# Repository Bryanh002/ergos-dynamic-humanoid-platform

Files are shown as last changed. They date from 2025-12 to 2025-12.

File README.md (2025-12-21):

```
███████╗██████╗  ██████╗  ██████╗ ███████╗
██╔════╝██╔══██╗██╔════╝ ██╔═══██╗██╔════╝
█████╗  ██████╔╝██║  ███╗██║   ██║███████╗
██╔══╝  ██╔══██╗██║   ██║██║   ██║╚════██║
███████╗██║  ██║╚██████╔╝╚██████╔╝███████║
╚══════╝╚═╝  ╚═╝ ╚═════╝  ╚═════╝ ╚══════╝
```
### Embodied Reinforcement Gait Optimization System
---

## 🧠 Overview
ERGOS is meant to be a low-cost, open-source platform designed for dynamic humanoid robotics research. It serves as a ROS2-based control environment that integrates serial servo hardware with Reinforcement Learning (RL) techniques. The primary goal of ERGOS is to develop and optimize dynamic, stable gait patterns for bipedal systems, demonstrating advanced movement capabilities on an economical, self-contained hardware platform. Here is a photo of ERGOS's current design:

<p align="center">
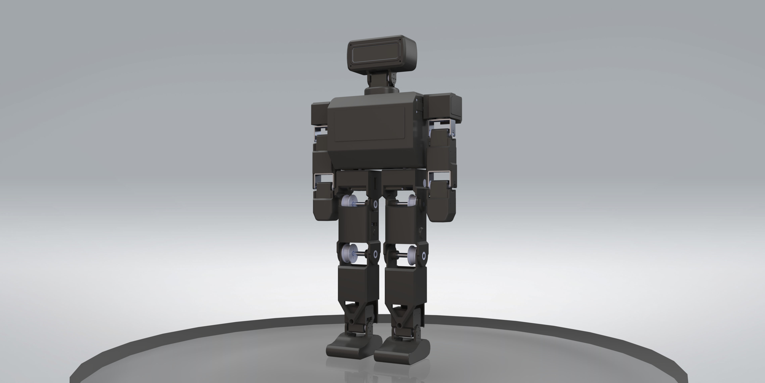
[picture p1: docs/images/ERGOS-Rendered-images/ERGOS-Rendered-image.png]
  
  <br>
</p>

---

## 🗺️ Repository Map

- **Hardware**
  - [`mechanical/`](mechanical/) — CAD, renders
  - [`electrical/`](electrical/) — schematics, PCB, BOM
- **Software**
  - [`software/`](software/) — firmware, ROS 2 packages, tools, simulations
- **Docs**
  - [`docs/`](docs/) — BOM, images, datasheets

---

## ⚙️ Features & Capabilities  
*(Planned and In Progress)*

### Mechanical System
- Custom humanoid mechanical design
- Belt-driven actuation using HTD-3M pulleys (18T–30T) for joint-specific torque amplification
- 3D-printed structural housings optimized for low cost and rapid iteration
- Modular joint architecture to support future actuator and transmission upgrades

### Electronics & Power
- Custom PCB featuring an ESP32-S3 for real-time servo communication
- Custom full-duplex to half-duplex TTL transceiver for serial servo bus control
- On-board power management from a 3S 8400 mAh LiPo battery
- Custom power and communication harness backbone for distributed serial servos
- Jetson Orin Nano as the primary compute module, interfacing with the MCU for control and perception workloads

### Dynamic Locomotion (Reinforcement Learning) *(Future)*
- Reinforcement learning-based locomotion control for stable, adaptive walking
- Simulation-first training pipeline with planned sim-to-real transfer onto physical hardware
- Architecture designed to support experimentation with different control formulations and reward structures

### Environmental Perception *(Future)*
- Vision system integration for obstacle detection and terrain awareness
- Planned fusion of perception outputs into locomotion and navigation policies

### Speech & Human Interaction *(Future)*
- On-board large language model (LLM) for voice-based command interpretation
- Natural-language interface for high-level behavior control and human–robot interactions

---

## 🧩 System Architecture

<p align="center">
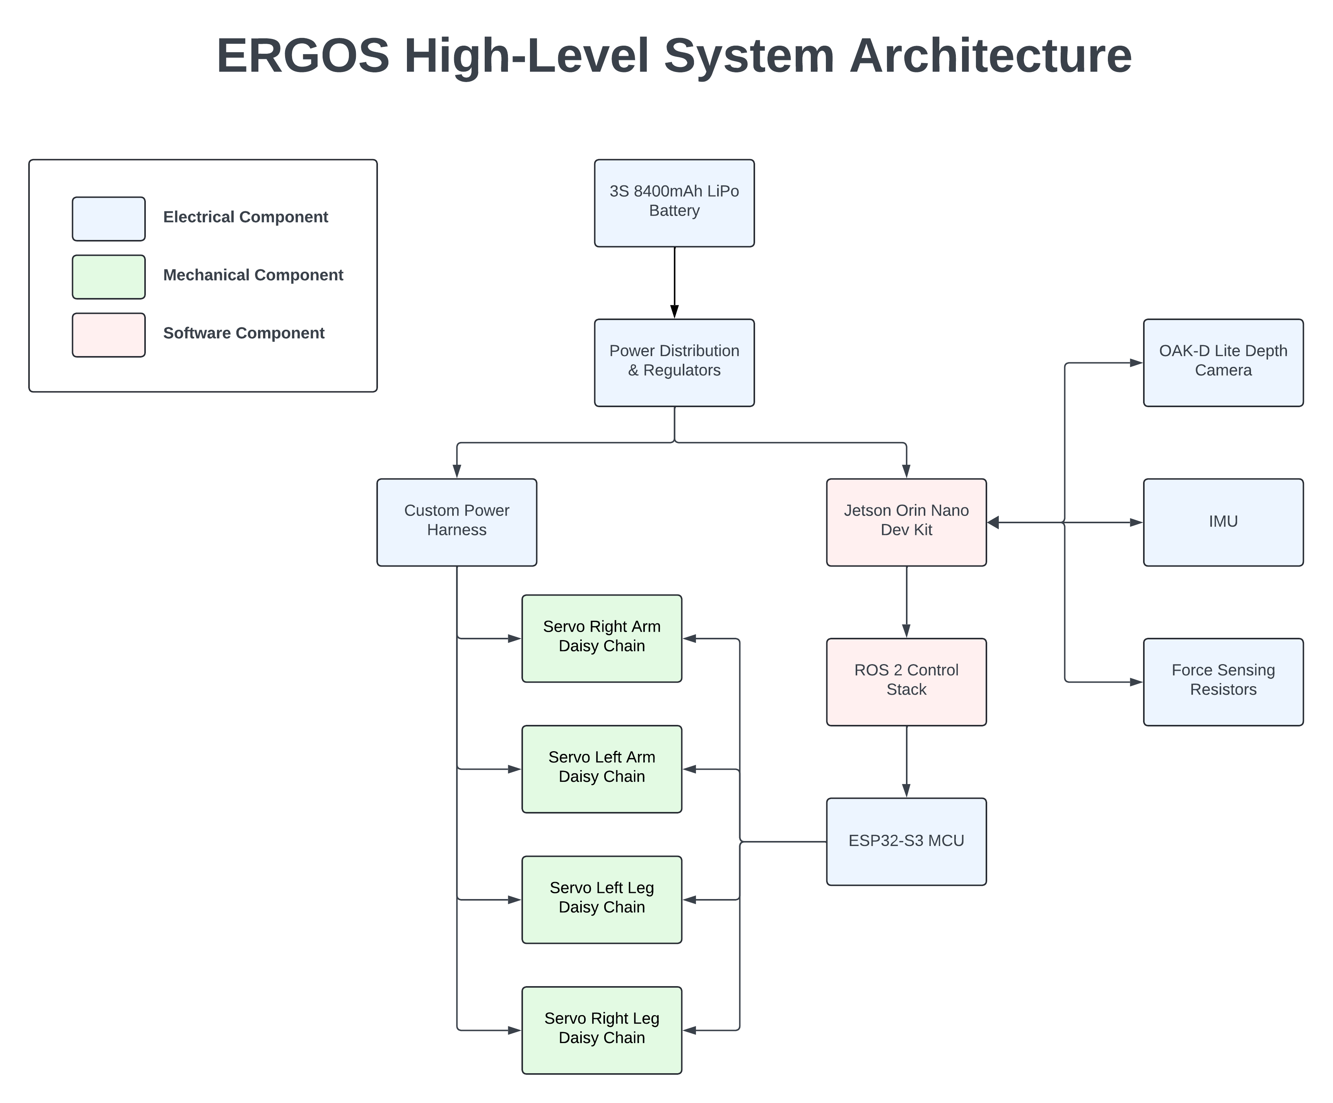
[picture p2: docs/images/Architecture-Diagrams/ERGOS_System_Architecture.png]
  
  <br>
</p>

**Figure 1.** High-level system architecture of the ERGOS humanoid platform. The system is powered by a centralized 3S LiPo battery, which feeds a custom power distribution and regulation stage. This stage supplies both the actuator subsystem and the main compute unit. High-level perception, planning, and reinforcement learning policies are executed on the Jetson Orin Nano within a ROS 2-based control stack. Control commands are transmitted to an ESP32-S3 real-time controller, which handles low-level actuation and interfaces directly with modular servo daisy chains. Sensor inputs, including depth vision, inertial measurements, and foot force sensing, are processed on the Jetson and integrated into the control pipeline. Detailed mechanical, electrical, and software architectures are documented in subsystem-specific sections.

---

## 🧪 Development Phases
1. **Phase 1 — Hardware Creation**  
   Finalize CAD design and PCB for servo control and power distribution.

3. **Phase 2 — Reinforcement Learning Simulation**  
   Develop a simulation environment for dynamic walking using RL.  
   *(Likely frameworks: PyTorch, custom physics simulation, or Isaac Gym)*

4. **Phase 3 — Real-World Testing**  
   Transfer trained model to the Jetson Orin Nano for live walking experiments.

5. **Phase 4 — Vision and Speech Integration**  
   Add camera input for object detection and LLM for high-level control.

---

## 🧠 Technical Summary
- **Programming Language:** Python (planned)
- **Frameworks:** TBD (PyTorch or TensorFlow for RL; ROS2 possible integration)
- **Hardware:** Jetson Orin Nano, ESP32-S3, Feetech STS3235/STS3250 smart servos
- **Design Tools:** SolidWorks (mechanical), Altium Designer (PCB)

---

## 🚀 Getting Started
*(To be updated as the project matures)*

**Planned sections:**
1. Installation requirements (JetPack SDK, Python environment, dependencies)
2. Simulation setup (RL environment)
3. Model training and deployment instructions
4. Hardware configuration and servo connection mapping

---

## 📈 Future Work
- WIP

---

## 📜 License
This project is open source and released under the **MIT License**.  
See the [LICENSE](LICENSE) file for more information.

---

## 👤 Project Developer
**Bryan Heddle**  
Mechatronics & AI Systems Engineering Student — *Western University*  

---

## 💡 Acknowledgments
Special thanks to the open-source robotics community for the tools, documentation, and inspiration that contributed to this project’s foundation.

**Project sponsors:**
- **[Thompson Innovation Fund](https://www.eng.uwo.ca/tc/innovation-fund.html)**
- **[WESEF](https://www.eng.uwo.ca/departments-units/finance-stores/undergrads/wesef.html)**
- **[Luxonis](https://www.luxonis.com/)**
---

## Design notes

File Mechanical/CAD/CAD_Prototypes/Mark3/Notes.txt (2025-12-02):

Make M2 screws to M3 (ones that connects torso to jetson holder)

Make 60KG servo wire holes

Make 12 mm bearing

Make wiring paths

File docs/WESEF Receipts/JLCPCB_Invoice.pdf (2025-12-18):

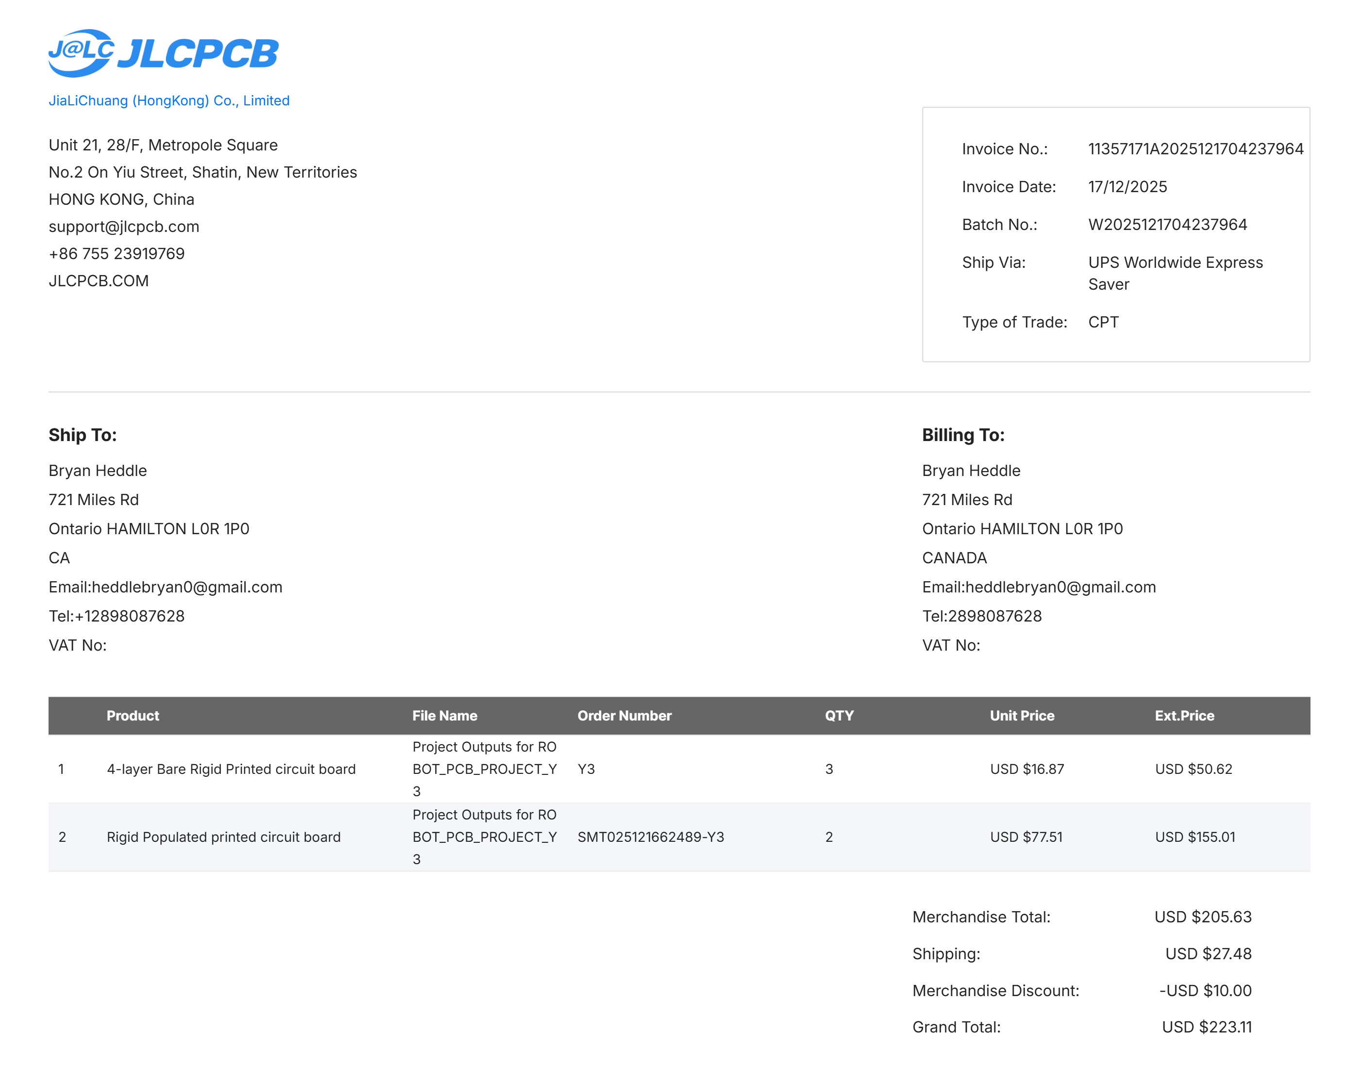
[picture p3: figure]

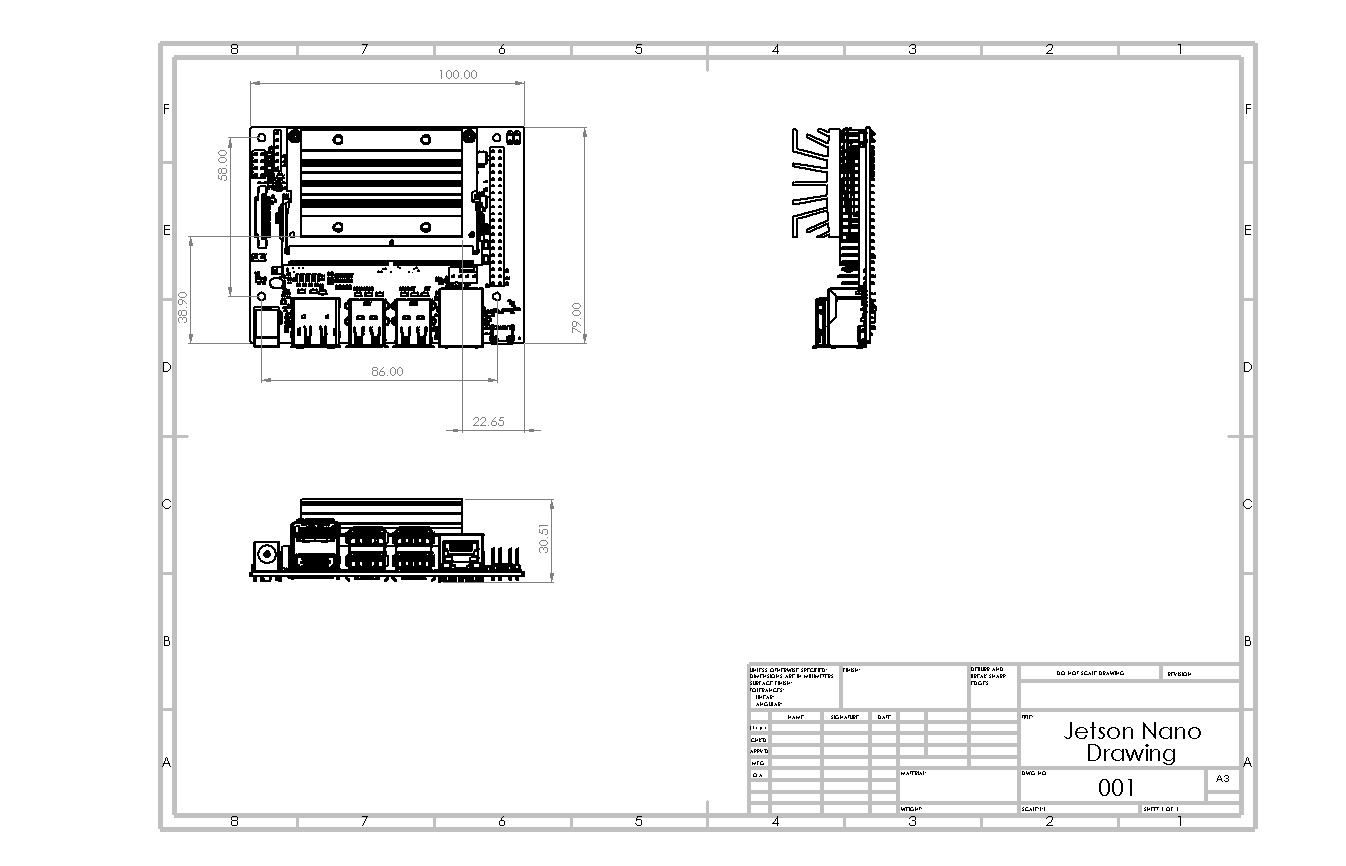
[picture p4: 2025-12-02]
Mechanical/CAD/CAD_Prototypes/Mark3/Drawings/Jetson_nano_4GB_Drawing.JPG

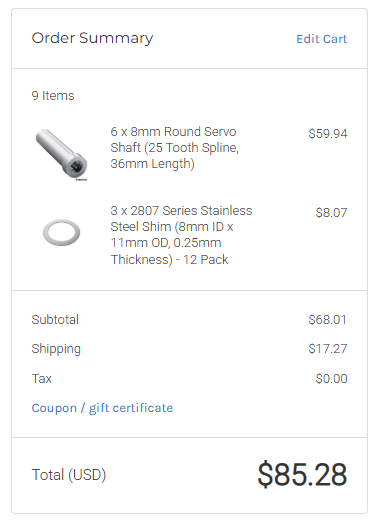
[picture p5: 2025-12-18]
docs/WESEF Receipts/Bilda-ServoShaft&Washers.PNG

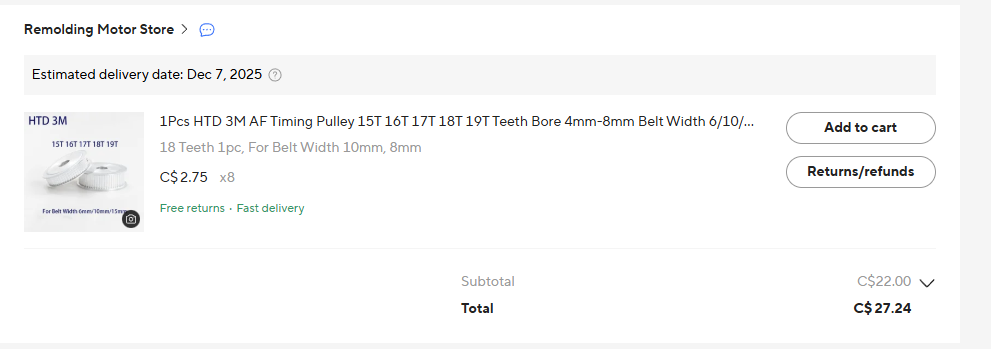
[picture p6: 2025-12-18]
docs/WESEF Receipts/AliExpress-18T-Pulley.PNG

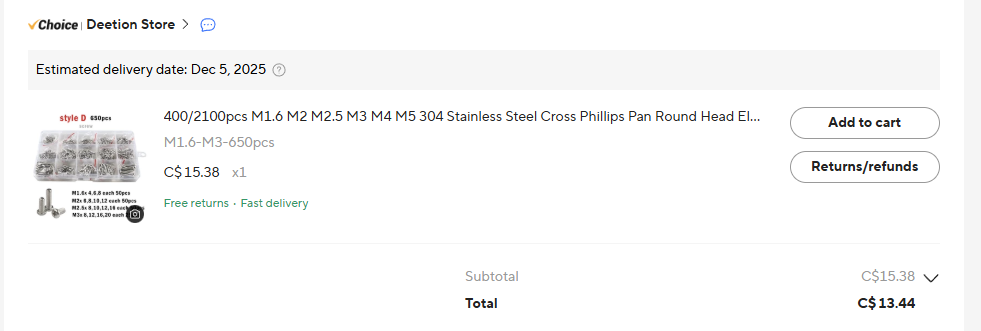
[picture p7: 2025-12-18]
docs/WESEF Receipts/AliExpress-ScrewKit.PNG

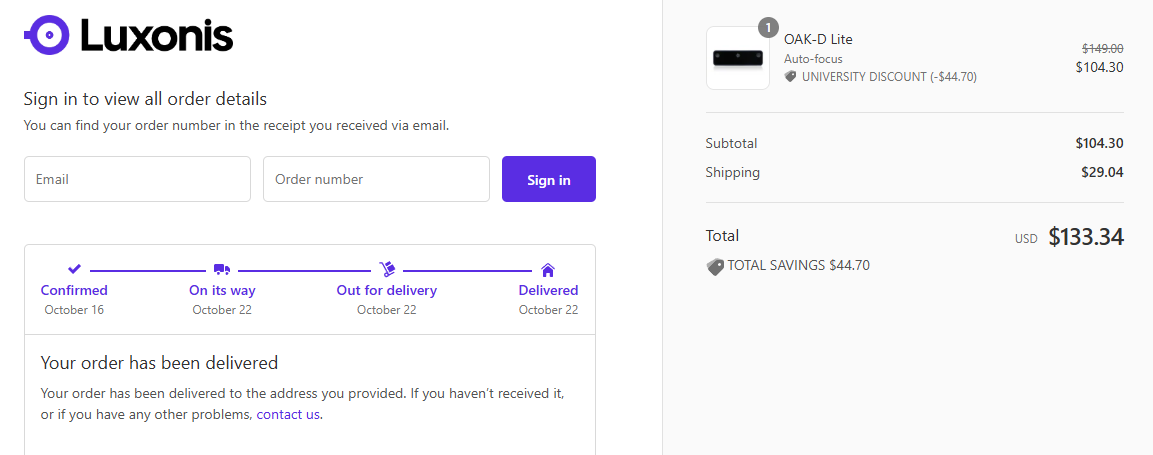
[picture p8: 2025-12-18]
docs/WESEF Receipts/Luxonis-OAK-D-Lite.PNG

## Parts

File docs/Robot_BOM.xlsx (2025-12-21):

Part | Product Link | Description | Quantity | Cost | Total Cost + Tax | Final Cost
MECHANICAL |  |  |  |  |  | $2960.02
STS3250 50kg-cm TTL Dual-shaft | https://www.feetechrc.com/en/562636.html | High-torque smart servo used for the hip, knee, and shoulder joints to handle the primary load-bearing and dynamic movement required for humanoid locomotion. | 14 | $65.81 | $1041.11
STS3235 30kg-cm TTL Dual-shaft | https://www.feetechrc.com/en/12v-30kg-metal-shell-metal-tooth-iron-core-motor-magnetic-coding-double-shaft-ttl-series-steering-gear.html | Medium-torque smart servo used for arm and neck joints where lower torque is sufficient but precise control is still required for coordinated movement. | 6 | $57.86 | $392.29
8mm Round Servo Shaft | https://www.gobilda.com/8mm-round-servo-shaft-25-tooth-spline-36mm-length/ | Custom shafts used to transfer motion between servo outputs and pulley assemblies, enabling reliable and backlash-free mechanical transmission. | 6 | $9.99 | $67.73
HTD 3M 18T Timing pulley | https://www.aliexpress.com/item/1005007456973949.html | Serves as the driving pulley in the belt transmission system, translating servo rotation. | 8 | $3.02 | $27.30
HTD 3M 30T Timing Pulley | https://www.aliexpress.com/item/1005009686443539.html | Acts as the driven pulley in the gear reduction setup, increasing torque at each joint. | 4 | $6.79 | $30.69
8mm ID 11 mm OD Washers | https://www.gobilda.com/2807-series-stainless-steel-shim-8mm-id-x-11mm-od-0-25mm-thickness-12-pack/ | Used to reduce axial friction and prevent rubbing between rotating parts and stationary brackets. | 1 | $2.69 | $3.04
MR95ZZ Bearings | https://www.amazon.ca/uxcell-Bearings-8x12x3-5mm-Miniature-Precision/dp/B0CM6G9ZKZ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 | Smaller bearings used in compact joint housings where load and speed requirements are moderate. | 1 | $16.29 | $18.41
PLA | https://www.amazon.ca/ELEGOO-Filament-Dimensional-Accuracy-Cardboard/dp/B0C8J1JZMT?s=industrial | 3D printing material used for lightweight housings and custom mounts throughout the robot prototype to allow iterative design, it's likely I'll need lots of PLA due to continous prints, and like mentioned, fixes. | 2 | $44.99 | $101.68
Loctite 638 | https://www.amazon.ca/Loctite-21448-Strength-Retaining-Compound/dp/B000O01EV0 | High-strength retaining compound for securing shafts, pulleys, and bearings, preventing slippage under dynamic loads. | 1 | $24 | $27.12
ELECTRICAL |  |  |  |  | 0
3s lipo 8400mah 11.1v 120c | https://www.amazon.ca/DXF-Battery-Hardcase-Airplane-Helicopter/dp/B09TDFVWHS | Primary power source for servos, Jetson Orin Nano, and sensors; provides sufficient current delivery for high-demand movements. | 1 | $99.99 | $112.99
PCB | JLCPCB [view quote image] | Central power and communication hub distributing regulated voltage and serial signals between servos, Jetson, and sensors. | 1 | $284.00 | $320.92
PCB components | https://www.digikey.ca/short/0zvnp1rd | all components required for PCB | 1 | $183 | $206.79
 |  |  |  |  | 0
SOFTWARE
Jetson Orin Nano | https://www.amazon.ca/NVIDIA-Jetson-Orin-Nano-Developer/dp/B0BZJTQ5YP | Main onboard computer handling perception, reinforcement learning, and motion planning in real time. | 1 | $344.95 | $389.79
OAK-D Lite | https://shop.luxonis.com/products/oak-d-lite-1 | Provides depth and RGB vision for environmental awareness, obstacle detection, and balance correction. Received 30% discount from Luxonis reducing the price from $209.8 to $147 CAD. | 1 | $146.84 | $165.93
Patriot P320 128GB SSD | https://www.amazon.ca/dp/B0D4RD18YV?ref=ppx_yo2ov_dt_b_fed_asin_title&th=1 | High-speed storage for AI models, video frames, and system data during real-time inference and logging. | 1 | $47.99 | $54.23

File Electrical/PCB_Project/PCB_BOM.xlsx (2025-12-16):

Line # | Name | Description | Designator | Revision ID | Quantity | Manufacturer 1 | Manufacturer Part Number 1 | Manufacturer Lifecycle 1 | Supplier 1 | Supplier Part Number 1 | Supplier Unit Price 1 | Supplier Subtotal 1 | JLCPCB
1 | SML-LX1206IC-TR | LED Red, 65 mW, -40 to 85 degC, 2-Pin SMD, RoHS, Tape and Reel | BLINK, PWR | CMP-2000-07123-1 | 2 | Lumex | SML-LX1206IC-TR | Volume Production | DigiKey | 67-1356-2-ND | 0.22 | 0.44
2 | 1825910-6 | Switch Push Button OFF (ON) SPST Round Button 0.05A 24VDC Momentary Contact PC Pins Thru-Hole | Boot1, Reset1 |  | 2 | TE Connectivity | 1825910-6 | Volume Production | Digikey | 450-1650-ND | 0.13 | 0.26
3 | CC0805KRX7R9BB104 | CAP CER 0.1UF 50V X7R 0805 | C1, C2, C5, C6, C7, C8, C9, C10, C11, C12, C13, C14, C15, C16, C17, C18, C19, Cboot1, Cboot2 | CMP-2100-03606-3 | 19 | Yageo Group | CC0805KRX7R9BB104 | Volume Production | Digikey | 311-1140-2-ND | 0.012 | 0.23
4 | C0805C105K5RACTU |  | C3, C4 | CMP-2007-03236-1 | 2 | KEMET | C0805C105K5RACTU | Volume Production | Mouser | 80-C0805C105K5R | 0.82507 | 1.65
5 | CGA4C2C0G1H822J060AA | Cap Ceramic 8.2nF 50V C0G 5% Pad SMD 0805 +125°C Automotive T/R | Ccomp1 | CMP-08246-000542-1 | 1 | TDK | CGA4C2C0G1H822J060AA | Volume Production | Arrow Electronics | CGA4C2C0G1H822J060AA | 0.01538 | 0.01538
6 | GRM1555C1H391JA01J | Chip Multilayer Ceramic Capacitors for General Purpose, 0402, 390pF, C0G, 30ppm/°C, 5%, 50V | Ccomp2 | CMP-2008-04006-2 | 1 | Murata | GRM1555C1H391JA01J | Volume Production | Mouser | 81-GRM1555C1H391JA1J | 0.13984 | 0.13984
7 | CL32A106KBJNNNE | Cap Ceramic 10uF 50V X5R ±10% SMD 1210 +85°C Embossed T/R | Cin1, Cin2 | CMP-13271-001337-1 | 2 | Samsung Electro-Mechanics | CL32A106KBJNNNE | Volume Production | DigiKey | 1276-3363-1-ND | 0.72718 | 1.45
8 | CL32B106KBJNNWE | Cap Ceramic 10uF 50V X7R ±10% SMD 1210 +125°C Embossed T/R | Cout1, Cout2, Cout3 | CMP-13271-004028-1 | 3 | Samsung Electro-Mechanics | CL32B106KBJNNWE | Volume Production | DigiKey | 1276-3388-6-ND | 0.30765 | 0.92296
9 | GRM1885C1H101JA01D | SMD Capacitor C0G(EIA) with Capacitance: 100pF Tol. 5%. Rated Voltage: 50Vdc | Csns | CMP-001-00083-1 | 1 | Murata | GRM1885C1H101JA01D | Not Recommended for New Design | DigiKey | 490-1427-2-ND | 0.08 | 0.08
10 | C1608C0G1E472J080AA | Multilayer Ceramic Capacitors 4.7nF ±5% 25V C0G SMD 0603 | Css | CMP-08246-004785-1 | 1 | TDK | C1608C0G1E472J080AA | Not Recommended for New Design | DigiKey | 445-2712-1-ND | 0.30765 | 0.30765
11 | GRM188R61C106MA73D | Chip Multilayer Ceramic Capacitors for General Purpose, 0603, 10uF, X5R, 15%, 20%, 16V | Cvcc | CMP-2006-02814-2 | 1 | Murata | GRM188R61C106MA73D | Volume Production | Mouser | 81-GRM188R61C106MA3D | 0.32164 | 0.32164
12 | GRM155R71C104KA88D | SMD Capacitor X7R(EIA) with Capacitance: 0.10uF Tol. 10%. Rated Voltage: 16Vdc | Cvin | CMP-001-00084-1 | 1 | Murata | GRM155R71C104KA88D | Volume Production | DigiKey | 490-3261-2-ND | 0.1 | 0.1
13 | SMBJ13A-13-F | 400 W 13 V Uni-Directional SMT Transient Voltage Suppressor Diode - DO-214AA | D2, D3, D4, D5 |  | 4 | Diodes Inc. | SMBJ13A-13-F | Volume Production | DigiKey | SMBJ13A-FDITR-ND | 0.28 | 1.12
14 | XBS053V15R-G | Diode Schottky 20V 500mA Surface Mount SOD-523 | Dboot | CMP-004-00031-1 | 1 | Torex | XBS053V15R-G | Volume Production | Mouser | 865-XBS053V15R-G | 1.07 | 1.07
15 | 3568 |  | F2, F3, F4, F5 | CMP-2000-05464-2 | 4 | Keystone | 3568 | Volume Production | Future Electronics | 4264032 | 1.06 | 4.22
16 | B3B-XH-A | Connector Header Through Hole 3 position 0.098 (2.50mm) | J1, J2, J3, J4 |  | 4 | JST Sales America Inc. | B3B-XH-A | Volume Production | DigiKey | 455-2248-ND | 0.11 | 0.44
17 | XT90PW-M | Socket; DC supply; XT90; male; PIN: 2; on PCBs; THT; Colour: yellow | J5 |  | 1 | DFRobot | FIT0588 | Volume Production | DigiKey | 1738-1438-ND | 3.9 | 3.9
18 | 1017505 |  | J6, J7 |  | 2 | Pheonix Contact | 1017505 | Volume Production | DigiKey | 277-17516-ND | 1.99 | 3.98
19 | KLDX-0202-B | 3 Conductor Power Jack, 2 break 2 aux contacts | J8 | CMP-0256-00001-1 | 1 | Kycon | KLDX-0202-B | Volume Production | DigiKey | 2092-KLDX-0202-B-ND | 0.96492 | 0.96492
20 | M20-9990246 | 2.54mm (0.1) Pitch SIL Vertical Throughboard Pin Header, 6.1mm mating pin height, tin, 2 contacts | J9, J10 | CMP-002-00071-1 | 2 | Harwin Inc. | M20-9990246 | Volume Production | DigiKey | 952-2262-ND | 0.1 | 0.2
21 | XAL6060-472MEC | Power inductor, shielded, 20% tol, SMT, RoHS, halogen-f | L1 | CMP-006-00021-1 | 1 | Coilcraft | XAL6060-472MEC | Volume Production | Mouser | 994-XAL6060-472MEC | 6.82 | 6.82
22 | CSD17571Q2 | MOSFET N-CH 30V 22A 6SON | Q1, Q2 | CMP-04962-000062-1 | 2 | Texas Instruments | CSD17571Q2 | Volume Production | Mouser | 595-CSD17571Q2 | 0.93695 | 1.87
23 | CRCW08054K70FKEA | RES Thick Film, 4.7kΩ, 1%, 0.125W, 100ppm/°C, 0805 | R1, R2, R3, R4, R5 | CMP-2100-03615-2 | 5 | Vishay | CRCW08054K70FKEA | Volume Production | RS (Formerly Allied Electronics) | 70201241 | 0.00839 | 0.04195
24 | RMCF0603FG47R0 | 47Ω ±1% 0.1W 0603 Thick Film Chip Resistor AEC-Q200 compliant | R6, R8, R10, R12 | CMP-26527-000678-1 | 4 | Stackpole Electronics | RMCF0603FG47R0 | Volume Production | Avnet | RMCF0603FG47R0 | 0.00266 | 26.57
25 | RMCF1206FG10K0 | 10kΩ ±1% 0.25W 1206 Thick Film Chip Resistor AEC-Q200 compliant | R7, R9, R11, R13, R14, R15 | CMP-26527-002036-1 | 6 | Stackpole Electronics | RMCF1206FG10K0 | Volume Production | DigiKey | 738-RMCF1206FG10K0CT-ND | 0.04055 | 0.40554
26 | CRCW04025K36FKED | RES Thick Film, 5.36kΩ, 1%, 0.063W, 100ppm/°C, 0402 | Rcomp | CMP-1011-00593-3 | 1 | Panasonic | ERJ-2RKF5361X | Volume Production | Arrow Electronics | ERJ-2RKF5361X | 0.00406 | 0.00406
27 | CRCW040211K0FKED | RES Thick Film, 11kΩ, 1%, 0.063W, 100ppm/°C, 0402 | Rfbb | CMP-2002-08157-2 | 1 | Vishay | CRCW040211K0FKED | Volume Production | DigiKey | 541-11.0KLCT-ND | 0.13984 | 0.13984
28 | 160K 1% 0603(1608) | 160K 0.1W 1% 0603 (1608 Metric) SMD | Rfbt | CMP-1012-00757-1 | 1 | Vishay | CRCW0603160KFKEA | Volume Production | Arrow Electronics | CRCW0603160KFKEA | 0.0014 | 0.0014
29 | CRCW040210R0FKED |  | Risns-, Risns+ | CMP-2002-08143-1 | 2 | Vishay | CRCW040210R0FKED | Volume Production | Mouser | 71-CRCW0402-10-E3 | 0.02237 | 0.22375
30 | CRCW0402100KFKED | RES Thick Film, 100kΩ, 1%, 0.063W, 100ppm/°C, 0402 | Rpg | CMP-2002-08123-3 | 1 | Vishay Dale | CRCW0402100KFKED | Volume Production | DigiKey | 541-100KLTR-ND | 0.1 | 0.1
31 | PRL1632-R010-F-T1 | 10 mOhms ±1% 1W Chip Resistor Wide 0612 (1632 Metric), Current Sense Thin Film | Rsns1, Rsns2 | CMP-2003-04764-2 | 2 | Susumu | PRL1632-R010-F-T1 | Volume Production | Mouser | 754-PRL1632-R010-FT1 | 0.65726 | 1.31
32 | RC0201FR-07105KL | 105 kOhms Â±1% 0.05W, 1/20W Chip Resistor 0201 (0603 Metric) Moisture Resistant Thick Film | Rt | CMP-009-00177-1 | 1 | Yageo Group | RC0201FR-07105KL | Volume Production | DigiKey | 311-105KMTR-ND | 0.1 | 0.1
33 | RC0201FR-07162KL | 162 kOhms Â±1% 0.05W, 1/20W Chip Resistor 0201 (0603 Metric) Moisture Resistant Thick Film | Ruvlo1 | CMP-009-00179-1 | 1 | Yageo Group | RC0201FR-07162KL | Volume Production | DigiKey | YAG2428TR-ND | 0.1 | 0.1
34 | RC0201FR-0723K7L | 23.7 kOhms Â±1% 0.05W, 1/20W Chip Resistor 0201 (0603 Metric) Moisture Resistant Thick Film | Ruvlo2 | CMP-009-00178-1 | 1 | Yageo Group | RC0201FR-0723K7L | Volume Production | DigiKey | YAG2524TR-ND | 0.1 | 0.1
35 | CRCW04022R00FKED |  | Rvcc | CMP-2002-08486-1 | 1 | Vishay | CRCW04022R00FKED | Volume Production | Newark | CRCW04022R00FKED | 0.00699 | 0.00699
36 | ESP32-S3-WROOM-1-N4R2 | Bluetooth, WiFi 802.11b/g/n, Bluetooth v5.0 Transceiver Module 2.4GHz PCB Trace Surface Mount | U1 |  | 1 | Espressif Systems | ESP32-S3-WROOM-1-N4R2 | Volume Production | DigiKey | 5407-ESP32-S3-WROOM-1-N4R2TR-ND | 5.28 | 5.28
37 | AP2112K-3.3TRG1 | IC REG LINEAR 3.3V 600MA SOT25 | U2 | CMP-12756-000035-1 | 1 | Diodes Inc. | AP2112K-3.3TRG1 | Volume Production | Arrow Electronics | AP2112K-3.3TRG1 | 0.10642 | 0.10642
38 | BMI323 | No Description Available | U3 |  | 1 | Bosch Sensortec | BMI323 | Volume Production | DigiKey | 828-BMI323TR-ND | 3.27 | 3.27
39 | SN74LVC2T45DCTR | 2-Bit Dual Supply Transceiver with Configurable Voltage-Level Shifting and 3-State Outputs 8-SSOP -40 to 85 | U4, U5 |  | 2 | Texas Instruments | SN74LVC2T45DCTR | Volume Production | DigiKey | 296-16845-2-ND | 0.56 | 1.12
40 | SN74LVC2G04DBVRG4 | IC INVERTER 2CH 2-INP SOT23-6 | U6 | CMP-04903-000086-1 | 1 | Texas Instruments | SN74LVC2G04DBVRG4 | Volume Production | Mouser | 595-74LVC2G04DBVRG4 | 1.09 | 1.09
41 | SN74AHCT1G125DBVT | Single 4.5-V to 5.5-V buffer with TTL-compatible CMOS inputs and 3-state outputs | U7, U8, U9, U10, U11, U12, U13, U14 |  | 8 | Texas Instruments | SN74AHCT1G125DBVT | Volume Production | DigiKey | 296-32243-2-ND | 0.84 | 6.72
42 | TPS43060RTER | IC REG CTRLR BOOST 16WQFN | U15 | CMP-04918-000522-1 | 1 | Texas Instruments | TPS43060RTER | Volume Production | DigiKey | 296-39400-1-ND | 3.97 | 3.97
43 | 105017-0001 | Micro-USB B Receptacle, Right Angle, Bottom Mount, Surface Mount, with Solder Tabs, -30 to 85 degC, 5-Pin USB, RoHS, Tape and Reel | VIN | CMP-2000-05827-1 | 1 | Molex | 105017-0001 | Volume Production | DigiKey | WM1399TR-ND | 0.92 | 0.92

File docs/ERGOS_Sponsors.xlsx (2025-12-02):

Sponsors | Amount | Type | Sponsor Link | Total
Thompson Innovation Fund | $1970 | Funding | https://www.eng.uwo.ca/tc/innovation-fund.html | $2782
Western Engineering Student Engagement Fund | $750 | Funding | https://www.eng.uwo.ca/departments-units/finance-stores/undergrads/wesef.html
Luxonis | $62 | Discount on Product | https://www.luxonis.com/

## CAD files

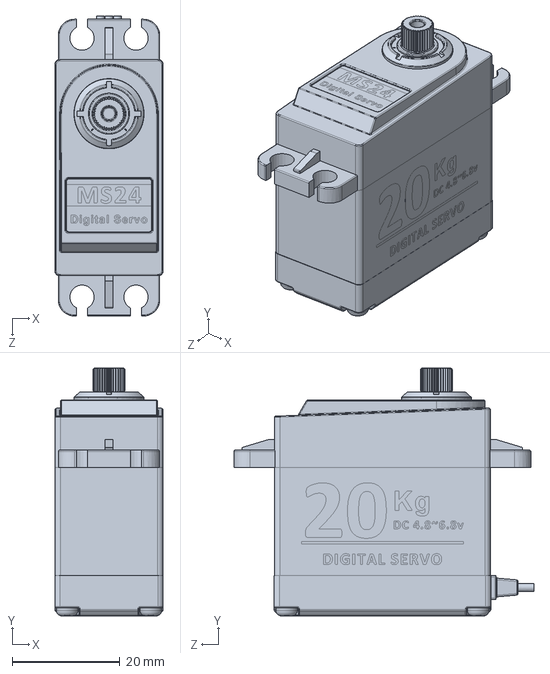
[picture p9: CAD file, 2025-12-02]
Mechanical/CAD/CAD_Prototypes/Mark3/Servos/DS3218MG MS24 Digital Servo 270.SLDPRT
20.1 x 45.9 x 55.6 mm

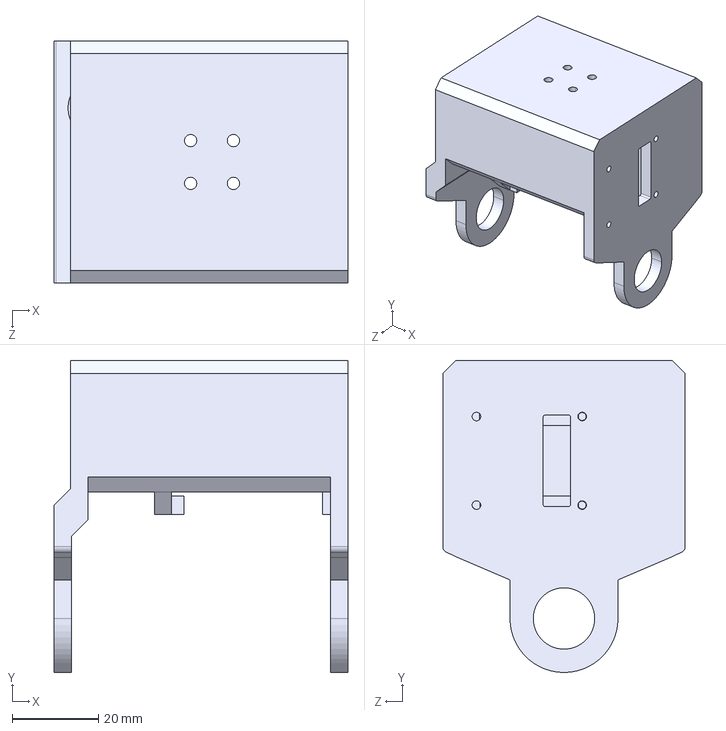
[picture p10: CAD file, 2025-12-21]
Mechanical/CAD/ERGOS_Mark4/Exports/Hip-pulley-housing-left.STEP
68.0 x 72.2 x 56.1 mm

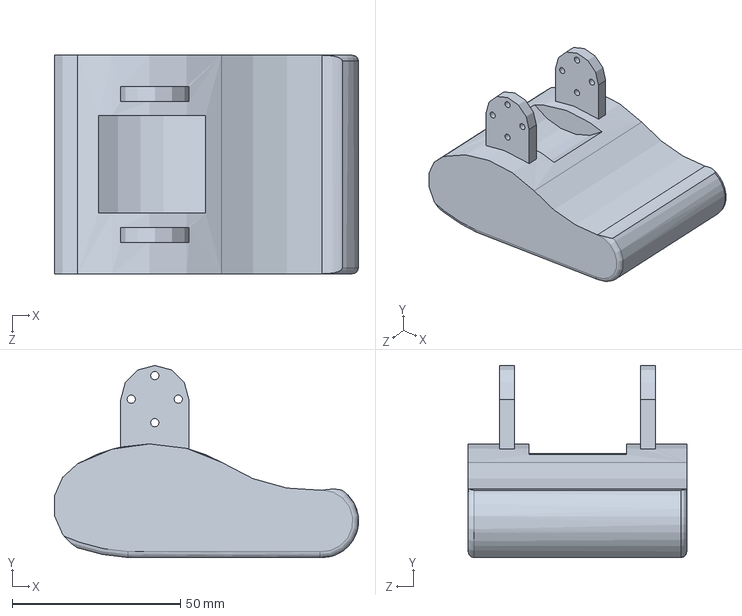
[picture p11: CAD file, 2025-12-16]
Mechanical/CAD/ERGOS_Mark4/Parts/Left-foot.SLDPRT
90.4 x 57.1 x 65.0 mm

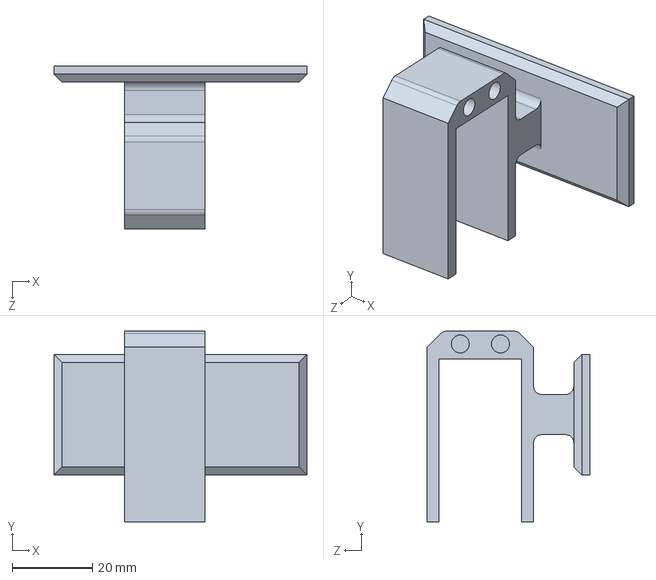
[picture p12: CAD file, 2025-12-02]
Mechanical/CAD/CAD_Prototypes/Mark3/Knee_Connector.SLDPRT
63.0 x 47.5 x 40.5 mm

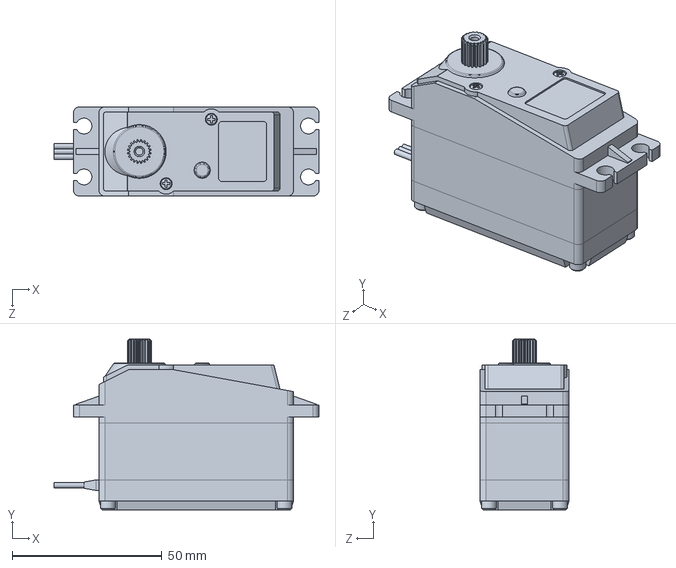
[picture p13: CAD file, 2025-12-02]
Mechanical/CAD/CAD_Prototypes/Mark3/Servos/DS5160ssg_60KG_Servo.SLDPRT
88.5 x 57.0 x 29.8 mm

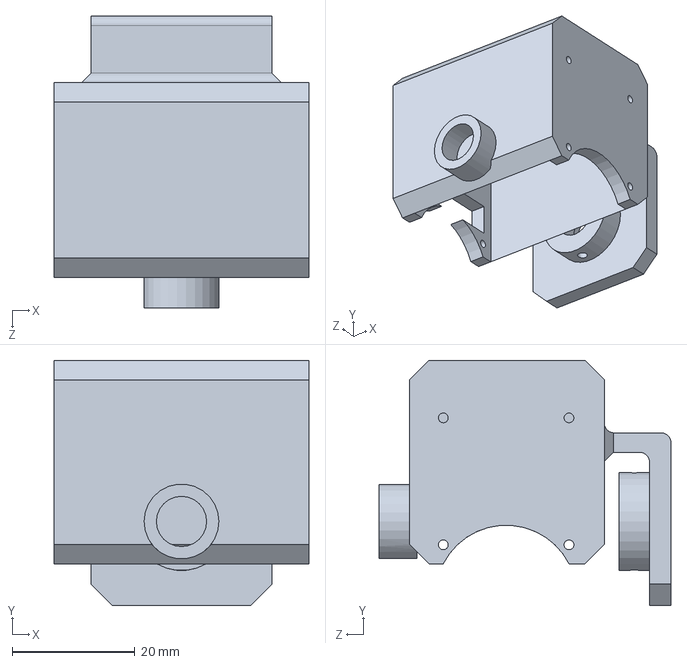
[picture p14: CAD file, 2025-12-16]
Mechanical/CAD/ERGOS_Mark4/Parts/Ankle-housing-right.SLDPRT
41.6 x 40.0 x 47.6 mm

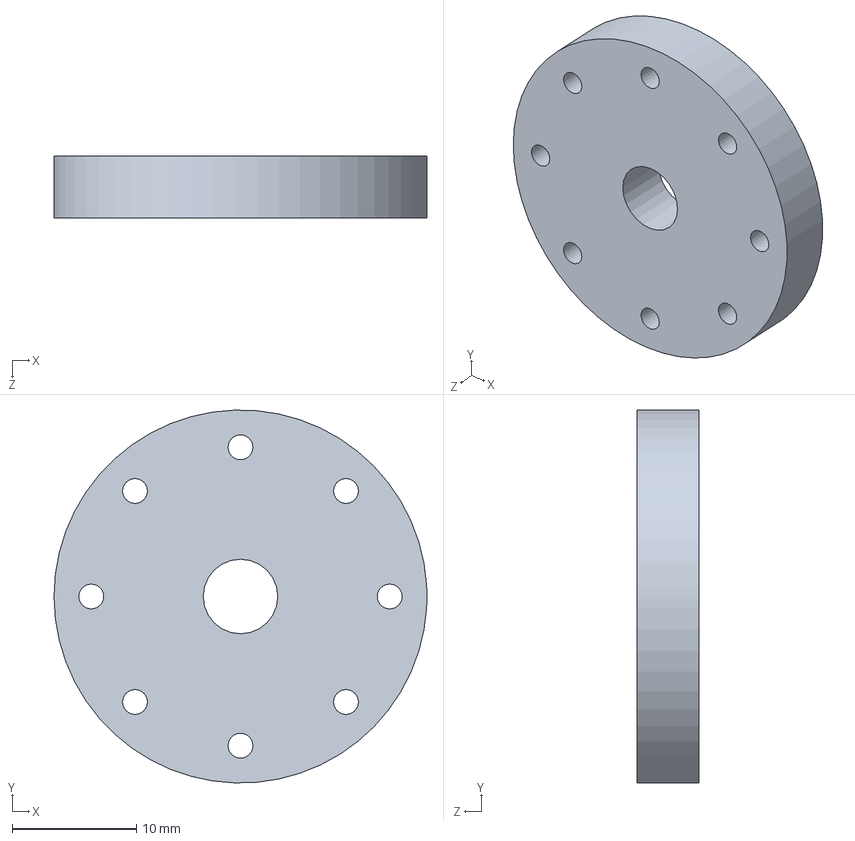
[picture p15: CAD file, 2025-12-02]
Mechanical/CAD/CAD_Prototypes/Mark3/Servo_Attachment.SLDPRT
30.0 x 30.0 x 5.00 mm

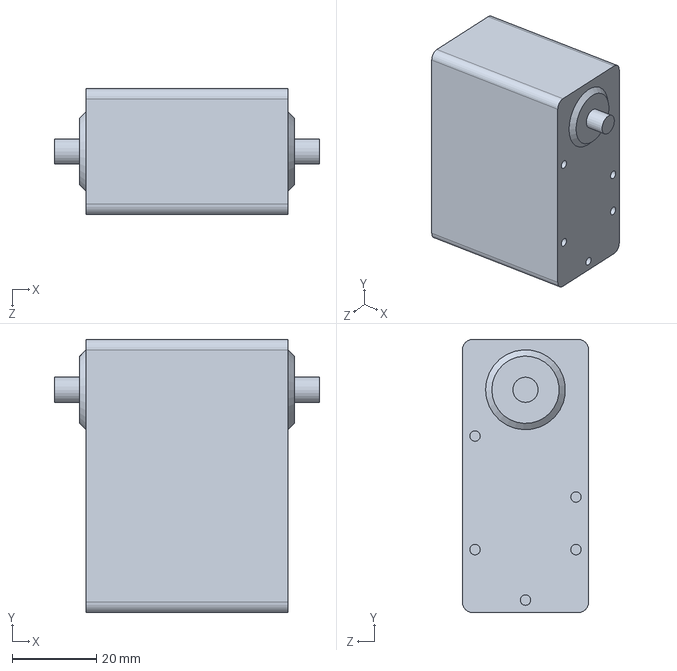
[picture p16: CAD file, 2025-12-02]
Mechanical/CAD/CAD_Prototypes/Mark3/Servos/WIP_60kg_Servo.SLDPRT
63.0 x 65.0 x 30.0 mm

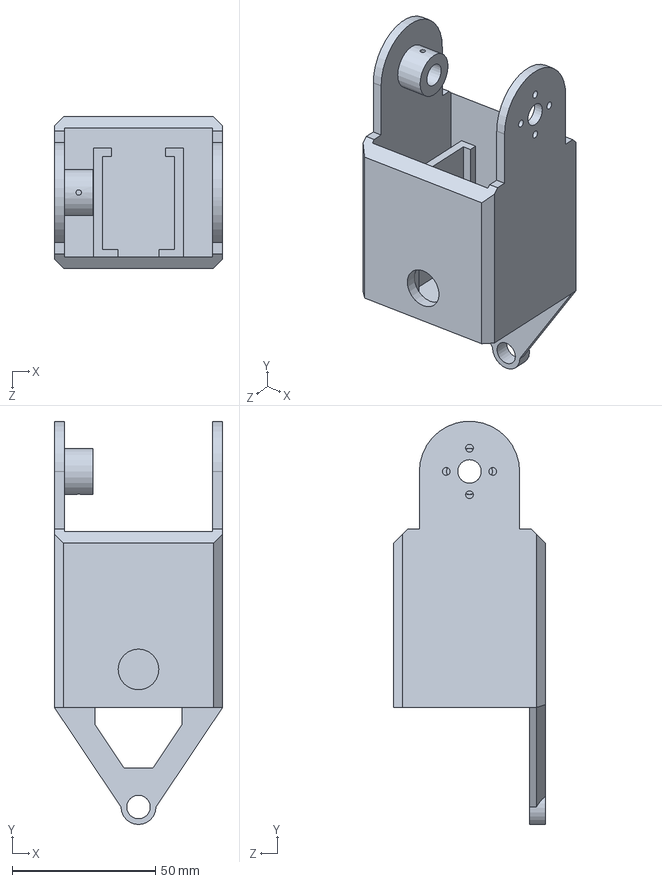
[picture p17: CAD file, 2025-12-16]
Mechanical/CAD/ERGOS_Mark4/Parts/Knee-housing-left.SLDPRT
58.7 x 140.6 x 53.0 mm

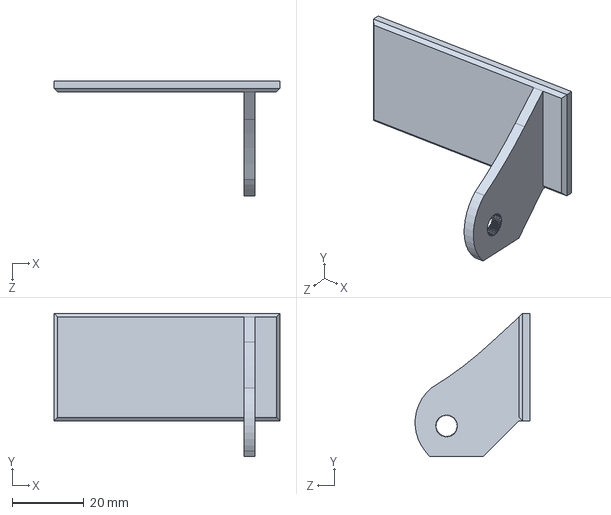
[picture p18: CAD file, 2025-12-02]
Mechanical/CAD/CAD_Prototypes/Mark3/Knee.SLDPRT
63.0 x 40.0 x 32.0 mm

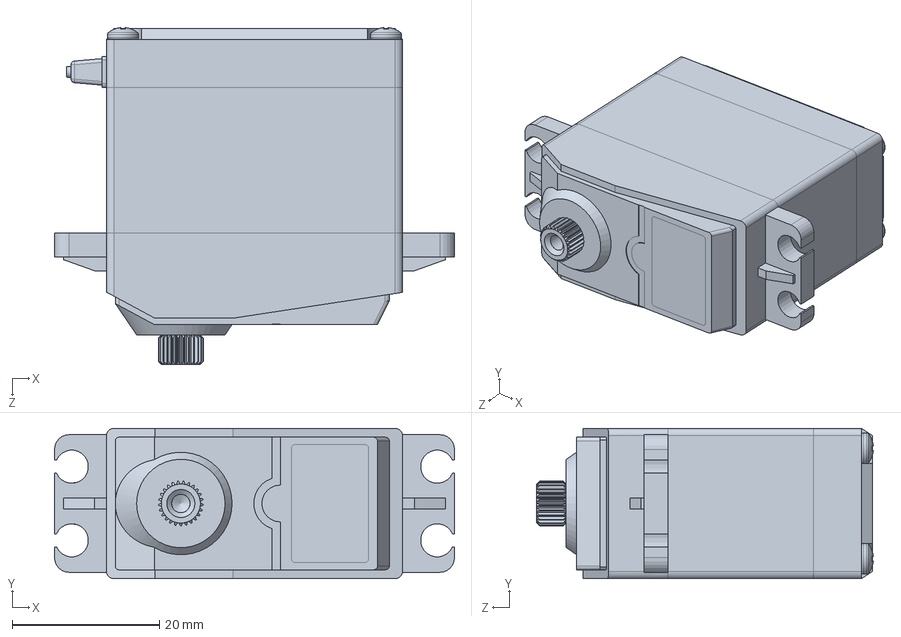
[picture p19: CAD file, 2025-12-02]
Mechanical/CAD/CAD_Prototypes/Mark3/Servos/DS3240_Servomotor 40Kg.SLDPRT
54.3 x 20.4 x 45.7 mm

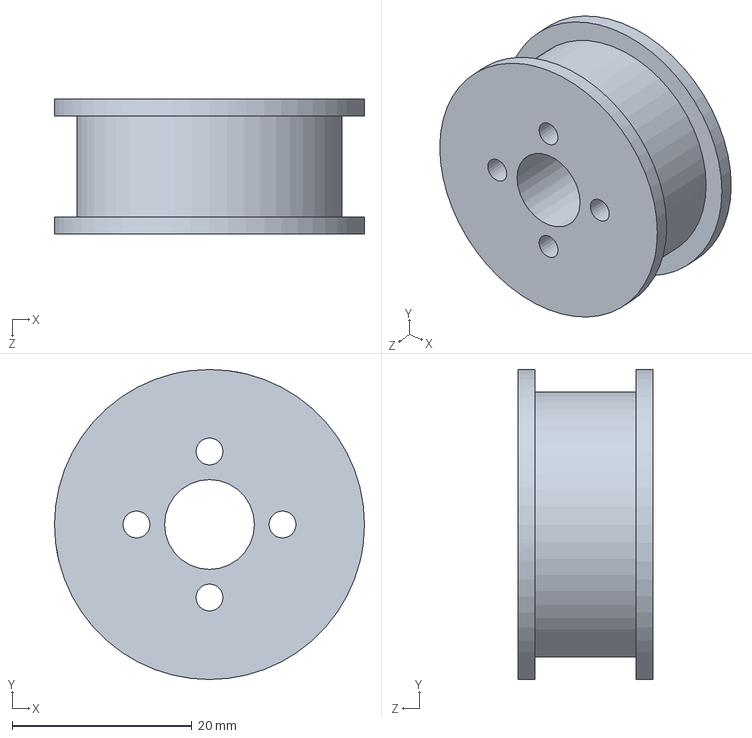
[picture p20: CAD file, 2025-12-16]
Mechanical/CAD/ERGOS_Mark4/Parts/HTD3M-30T-10mm.SLDPRT
34.5 x 34.5 x 15.0 mm

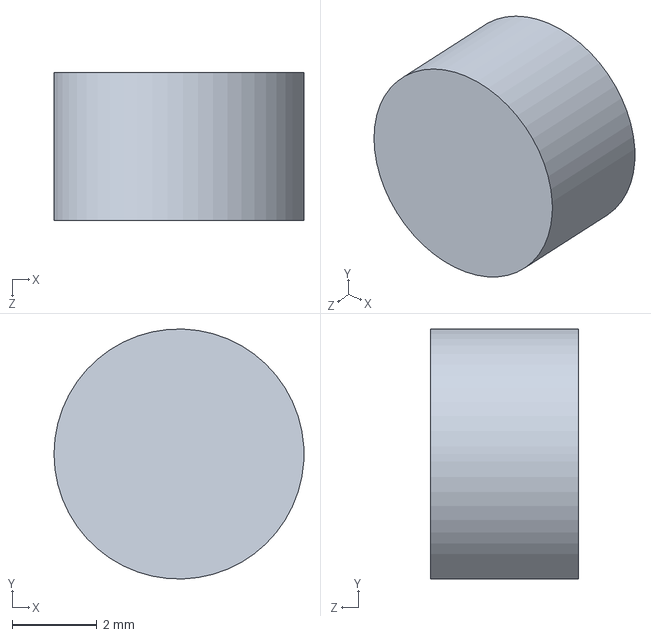
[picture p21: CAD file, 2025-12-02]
Mechanical/CAD/CAD_Prototypes/Mark3/Knee_Bearing_Mount.SLDPRT
5.90 x 5.90 x 3.50 mm

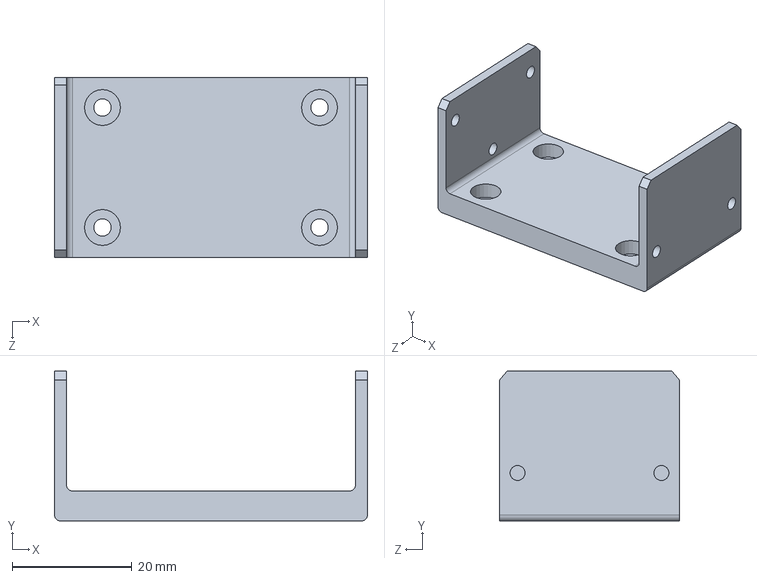
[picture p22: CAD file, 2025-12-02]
Mechanical/CAD/CAD_Prototypes/Mark3/Elbow_Mount.SLDPRT
52.2 x 25.0 x 30.0 mm

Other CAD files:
Mechanical/CAD/ERGOS_Mark4/Assemblies/Servo-to-shaft.SLDASM
Mechanical/CAD/CAD_Prototypes/Mark3/MirrorLeft-foot.SLDPRT
Mechanical/CAD/ERGOS_Mark4/Parts/Ankle-housing-left.SLDPRT
Mechanical/CAD/ERGOS_Mark4/Parts/HTD3M-18T-8mm.SLDPRT
Mechanical/CAD/CAD_Prototypes/Mark1/Arm.SLDPRT
Mechanical/CAD/CAD_Prototypes/Mark1/ForeArm.SLDPRT
Mechanical/CAD/CAD_Prototypes/Mark1/Hip.SLDPRT
Mechanical/CAD/CAD_Prototypes/Mark1/Quad.SLDPRT
Mechanical/CAD/CAD_Prototypes/Mark1/Robot_Assembly.SLDASM
Mechanical/CAD/CAD_Prototypes/Mark1/Shin.SLDPRT
Mechanical/CAD/CAD_Prototypes/Mark1/Torso.SLDPRT
Mechanical/CAD/CAD_Prototypes/Mark2/Torso.SLDPRT
Mechanical/CAD/CAD_Prototypes/Mark3/Ankle_Bearing_Mount.SLDPRT
Mechanical/CAD/CAD_Prototypes/Mark3/Ankle_Connector.SLDPRT
Mechanical/CAD/CAD_Prototypes/Mark3/Battery.SLDPRT
Mechanical/CAD/CAD_Prototypes/Mark3/Battery_Mounter.SLDPRT
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

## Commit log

2025-09-19 Uploading MARK4 to github
    [5mm-aluminum-shaft.SLDPRT, 5mm-aluminum-shaft2.SLDPRT, 5mm-aluminum-shaft3.SLDPRT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]
2025-09-26 Add PCB project!
    [AI_PCB_PROJECT.PrjPcb, Jetson_power.SchDoc, MCU_IMU.SchDoc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]
2025-11-11 Major update
    [5mm-aluminum-shaft2.SLDPRT, 5mm-aluminum-shaft3.SLDPRT, AI_PCB_PROJECT.PrjPcb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]
2025-11-16 Start of new assembly
    [Chassis.SLDPRT, Jetson-orin-mounter-case.SLDPRT, Jetson-orin-nano-mounter.SLDPRT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]
2025-12-02 project structure rework
    [12mm Bearing.SLDPRT, 5mm-aluminum-shaft.SLDPRT, 5mm-aluminum-shaft2.SLDPRT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]
2025-12-02 Added sponsors list
    [ERGOS_Sponsors.xlsx]
2025-12-03 Updated folder names
    [ERGOS_Sponsors.xlsx, Jetson_power.SchDoc, Robot_BOM.xlsx]
2025-12-16 Finalized CAD and added Visualize
    [5mm-aluminum-shaft.SLDPRT, 5mm-aluminum-shaft2.SLDPRT, 5mm-aluminum-shaft3.SLDPRT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]
2025-12-18 New rendered image
    [Jetson_power.SchDoc, Pick Place for ROBOT_MOTHERBOARD.csv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]
2025-12-18 Edited repository structure
    [12mm Bearing.SLDPRT, 5mm-aluminum-shaft.SLDPRT, 5mm-aluminum-shaft2.SLDPRT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]
2025-12-21 Re-organized project structure V1
    [Jetson_power.SchDoc, MCU_IMU.SchDoc, Pick Place for ROBOT_MOTHERBOARD.csv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]
2025-12-21 Add Bill of Materials (BOM) to README
    Added a comprehensive Bill of Materials (BOM) for the project, detailing mechanical, electrical, and software components with descriptions, quantities, and costs.
2025-12-21 Added system architecture flow charts
    [Hip-pulley-housing-left.SLDPRT, Hip-pulley-housing-left.STEP, Robot_BOM.xlsx]
2025-12-21 Revise Figure 1 description in README
    Updated the description of Figure 1 to provide a detailed overview of the ERGOS humanoid platform's architecture, including power distribution, control systems, and sensor integration.
2025-12-21 Re-organized electrical directory
    [PCB_BOM.xlsx, Pick Place for ROBOT_MOTHERBOARD.csv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]
